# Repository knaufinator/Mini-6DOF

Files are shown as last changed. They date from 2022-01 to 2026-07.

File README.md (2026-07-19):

# Mini-6DOF Stewart Platform

> ## ⚠️ ARCHIVED — this firmware has moved
> The Mini-6DOF firmware now lives in the **unified 6DOF repo** as the **`mini/` variant**, sharing the
> `stewart-core` submodule with the full-system `Controller/` firmware:
> **→ [6DOF-Rotary-Stewart-Motion-Simulator › `mini/`](https://github.com/knaufinator/6DOF-Rotary-Stewart-Motion-Simulator/tree/phoenix/mini)**
> (see [`FIRMWARE.md`](https://github.com/knaufinator/6DOF-Rotary-Stewart-Motion-Simulator/blob/phoenix/FIRMWARE.md) for the variant map).
> This repository is **read-only / no longer active** — all new work (incl. the Phase-3 on-ESP cue engine,
> SOURCE modes, M6P2, and `SERVO:RATE`) happens in the unified repo. Kept for history.





> Desktop-scale 6-DOF Stewart platform powered by hobby servos and an ESP32, running production firmware derived from the [full-scale 6DOF Rotary Stewart Motion Simulator](https://github.com/knaufinator/6DOF-Rotary-Stewart-Motion-Simulator).

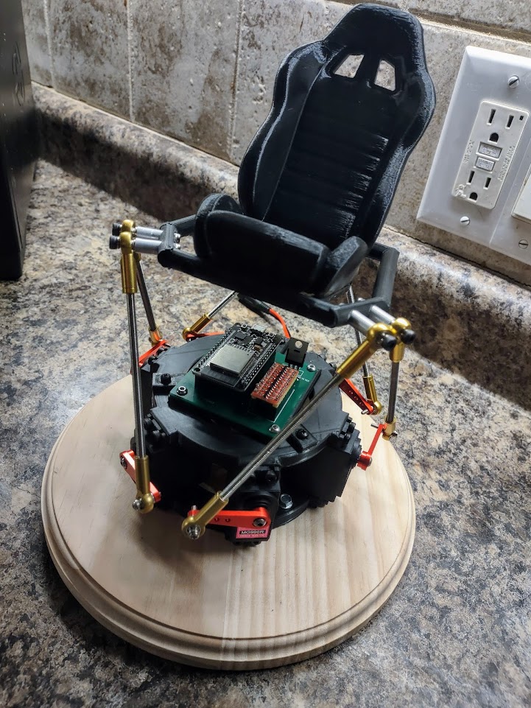
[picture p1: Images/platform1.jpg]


## Overview

The Mini-6DOF is a compact Stewart platform designed for development, testing, and education. It shares the same inverse kinematics engine, serial command API, and binary communication protocol as the full-scale platform — making it a drop-in test bed for firmware and desktop app development.

The `Controller/` firmware is a native ESP-IDF v5.2 project (phoenix branch rewrite) that replaces the original Arduino sketch with a production-grade implementation featuring proper IK workspace probing, binary protocol support, and full compatibility with the [desktop HIL control app](https://github.com/knaufinator/6DOF-Rotary-Stewart-Motion-Simulator/tree/main/app).

### What's New (Phoenix Branch)

- **ESP-IDF native firmware** — replaced Arduino `.ino` with proper ESP-IDF v5.2 project
- **Shared IK engine** — same `InverseKinematics.cpp` and `AxisScaling.cpp` as the full-scale controller
- **Automatic workspace probing** — axis scales computed from geometry, no manual tuning
- **Binary protocol** — 15-byte framed packets (0xAA/0x55 + 6×uint16 LE + XOR checksum) at up to 1000 Hz
- **Unified command API** — `VERSION?`, `FINGERPRINT?`, `CONFIG?`, `SCALE?`, `BITS?`, `ZERO`, `ESTOP:SOFT`
- **Desktop app compatible** — works as an HIL entity in the native C++/ImGui control app
- **Runtime configurable** — geometry, servo calibration, bit depth, axis scales — all adjustable over serial

## Repository Layout

| Directory | Contents |
|---|---|
| `Controller/` | **ESP-IDF v5.2 firmware** (production) — see [Controller/README.md](Controller/README.md) |
| `MiniServoController/` | Original Arduino sketch (legacy reference, not maintained) |
| `Android/` | **Android BLE controller app** (Jetpack Compose, phone-as-controller) |
| `3D Parts/` | STL files for 3D-printed servo mounts and seat rails |
| `PCB/` | Custom PCB gerbers and BOM |
| `Images/` | Project photos |

## Quick Start

```bash
# 1. Clone
git clone https://github.com/knaufinator/Mini-6DOF.git
cd Mini-6DOF/Controller

# 2. Build & flash (requires ESP-IDF v5.2)
idf.py set-target esp32
idf.py build
idf.py -p COM6 flash monitor
```

See [Controller/README.md](Controller/README.md) for full build instructions, pinout, and serial commands.

## Hardware

- **MCU**: ESP32 DevKitC (original ESP32, not S3)
- **Servos**: 6 × hobby servos (50 Hz PWM, 800–2200 µs pulse range)
- **Power**: 5V 8A supply for servo rail
- **Servo Enable**: GPIO 27 controls power relay/MOSFET for servo rail
- **Frame**: 3D-printed mounts + Panhard-style linkage rods

### Servo Pinout

| Servo | GPIO | Inverted |
|---|---|---|
| 0 | 15 | Yes |
| 1 | 14 | No |
| 2 | 4 | Yes |
| 3 | 32 | No |
| 4 | 33 | Yes |
| 5 | 5 | No |

### Platform Geometry (mm)

| Parameter | Value | Description |
|---|---|---|
| RD | 15.75 | Base radius |
| PD | 16.00 | Platform radius |
| L1 | 7.25 | Servo horn length |
| L2 | 28.50 | Connecting rod length |
| H | 25.517 | Neutral platform height |
| θ_r | 10° | Base rotation angle |
| θ_p | 30° | Platform rotation angle |

## Android App (Phone-as-Controller)

The `Android/` directory contains a Jetpack Compose BLE controller app that turns your phone into a 6-DOF motion controller. The phone's orientation sensors and accelerometer drive the platform in real time over BLE.

### Features

- **6-axis control** — roll, pitch, yaw from phone orientation; surge, sway, heave from accelerometer
- **Per-axis tuning** — individual enable, scale (0.01–2.0×), and invert toggles for all 6 axes
- **Max angle clamp** — adjustable 1–6° limit on rotation axes
- **Live data display** — real-time sent values shown per axis
- **Send rate** — configurable 1–200 Hz BLE packet rate
- **Persistent settings** — all axis config saved to SharedPreferences, restored on launch
- **Zero/reset** — one-tap reference reset and home button
- **Manual sliders** — 6-axis manual control when not streaming orientation

### BLE Protocol

The app communicates via two BLE characteristics:

| Characteristic | UUID | Payload | Purpose |
|---|---|---|---|
| Motion | `0xFF01` | 12 bytes: 6 × uint16 LE (0–4095) | Manual slider / IMU percent mode |
| Accel | `0xFF03` | 24 bytes: 6 × float32 LE | Orientation + accel (phone-as-controller) |

**Accel characteristic format** (preferred):

| Float | Field | Unit | Source |
|---|---|---|---|
| 0 | Roll | degrees | Phone orientation (game rotation vector) |
| 1 | Pitch | degrees | Phone orientation |
| 2 | Yaw | degrees | Phone orientation |
| 3 | Surge | m/s² | Accelerometer X |
| 4 | Sway | m/s² | Accelerometer Y |
| 5 | Heave | m/s² | Accelerometer Z (gravity subtracted) |

### Building the APK

Open `Android/` in Android Studio, sync Gradle, and build. Requires Android SDK 34+ and a phone with BLE + accelerometer + gyroscope.

### Default Axis Config

| Axis | Enabled | Scale | Notes |
|---|---|---|---|
| Roll | ✓ | 0.50 | Phone tilt left/right |
| Pitch | ✓ | 0.50 | Phone tilt forward/back |
| Yaw | ✗ | 0.50 | Disabled by default (gyro drift) |
| Surge | ✗ | 0.30 | Phone accel X → platform forward/back |
| Sway | ✗ | 0.30 | Phone accel Y → platform left/right |
| Heave | ✗ | 0.30 | Phone accel Z → platform up/down |

## Communication

### Serial (USB CDC) — 115200 baud, 8N1

**Binary (preferred — 15 bytes, up to 1000 Hz):**

| Offset | Size | Field |
|---|---|---|
| 0 | 1 | `0xAA` sync |
| 1 | 1 | `0x55` sync |
| 2 | 12 | 6 × `uint16_t` LE — surge, sway, heave, pitch, roll, yaw (0–4095 default) |
| 14 | 1 | XOR checksum of bytes 2–13 |

**Legacy CSV:** `<v0>,<v1>,<v2>,<v3>,<v4>,<v5>X`

Both protocols are handled simultaneously. The binary packet state machine takes priority; ASCII bytes fall through to the CSV/command parser.

### SimTools Setup

| Setting | Value |
|---|---|
| Interface Type | Serial |
| COM Port | (your ESP32 port, e.g. COM6) |
| Baud Rate | 115200 |
| Output - Bit Range | 12 |
| Output - Type | Decimal |
| Axis Mapping | `x, y, z, Ry, Rx, Rz` |
| Output Format | `<Axis1a>,<Axis2a>,<Axis3a>,<Axis4a>,<Axis5a>,<Axis6a>X` |

### Desktop App (HIL Mode)

The Mini-6DOF works as an HIL entity in the [native desktop app](https://github.com/knaufinator/6DOF-Rotary-Stewart-Motion-Simulator/tree/main/app). The app auto-detects the platform via `FINGERPRINT?` (reports `platform=mini-6dof`) and loads appropriate geometry defaults.

## Serial Commands

All commands use `X` or newline as terminator.

| Command | Response | Description |
|---|---|---|
| `VERSION?` | `VERSION:1.0.0,proto=1,platform=mini-6dof,...` | Firmware version |
| `FINGERPRINT?` | `FINGERPRINT:<MAC>,fw=1.0.0,proto=1,platform=mini-6dof` | Device identity |
| `CONFIG?` | Geometry + servo calibration | Full platform config dump |
| `CONFIG:key=value` | `CONFIG:OK key=value` | Set geometry param (RD, PD, L1, L2, height, theta_r, theta_p) |
| `SCALE?` | `SCALE:s0,s1,s2,s3,s4,s5` | Current axis scales |
| `BITS?` | `BITS:12,max_raw=4095` | Current input bit depth |
| `BITS:N` | `BITS:N,max_raw=...` | Set bit depth (8–16) |
| `SERVO:CENTER=c0,...,c5` | Echo new centers | Calibrate servo center positions (µs) |
| `SERVO:PULSE=value` | Echo new value | Set pulse-per-radian multiplier |
| `ZERO` | `ZERO:OK` | Home all servos to center |
| `ESTOP:SOFT` | Confirmation | Emergency return to center |
| `DBG:1` / `DBG:0` | Confirmation | Enable/disable debug output |

## Relationship to Full-Scale Platform

This project is the desktop-scale companion to the [6DOF Rotary Stewart Motion Simulator](https://github.com/knaufinator/6DOF-Rotary-Stewart-Motion-Simulator). The firmware shares:

- **Inverse kinematics** — same `InverseKinematics.cpp/.h` (Eisele closed-form solution)
- **Axis scaling** — same `AxisScaling.cpp/.h` (geometry-based workspace probing)
- **Serial protocol** — same binary packet format and command API
- **Platform identification** — `FINGERPRINT?` returns `platform=mini-6dof` so the desktop app can distinguish it from the full-scale `platform=stewart-6dof`

The key differences are output stage (LEDC PWM for hobby servos vs. MCPWM step/dir for AC servos) and scale (millimeters vs. hundreds of millimeters).

## License

MIT — see [LICENSE](LICENSE).

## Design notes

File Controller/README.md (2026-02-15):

# Mini-6DOF Controller Firmware

ESP-IDF v5.2 firmware for the ESP32 driving 6 hobby servos via LEDC PWM in a Stewart platform configuration.

## Project Structure

```
Controller/
├── main/
│   ├── main.cpp              # app_main entry point, FreeRTOS tasks, command API
│   ├── InverseKinematics.cpp # Stewart platform IK solver (shared with full-scale)
│   ├── AxisScaling.cpp       # Per-axis scaling + mapRawToPosition() (shared)
│   ├── BleTransport.cpp      # BLE GATT server (motion + accel characteristics)
│   ├── helpers.cpp           # mapfloat utility
│   └── CMakeLists.txt        # Component build config
├── include/
│   ├── InverseKinematics.h   # StewartConfig + PlatformDef structs, IK API
│   ├── AxisScaling.h         # AxisScaleConfig struct, workspace probing API
│   ├── helpers.h             # Pin definitions, servo parameters, timing constants
│   ├── version.h             # Firmware version + platform ID ("mini-6dof")
│   └── debug_uart.h          # Compile-time debug gating (DBG:1 / DBG:0)
├── CMakeLists.txt            # Top-level ESP-IDF project
└── sdkconfig.defaults        # ESP32 config (UART console, FreeRTOS 1kHz)
```

## Hardware

- **MCU**: ESP32 DevKitC (original ESP32 — not ESP32-S3)
- **Servos**: 6 × hobby servos (SG90/MG996R class)
- **PWM**: LEDC peripheral at 50 Hz, 16-bit resolution (~0.3 µs per tick)
- **Pulse range**: 800–2200 µs (center: 1500 µs)
- **Servo enable**: GPIO 27 — controls power relay/MOSFET for servo rail

### Pinout

| Servo | GPIO | LEDC Channel | Inverted |
|---|---|---|---|
| 0 | 15 | 0 | Yes |
| 1 | 14 | 1 | No |
| 2 | 4 | 2 | Yes |
| 3 | 32 | 3 | No |
| 4 | 33 | 4 | Yes |
| 5 | 5 | 5 | No |

| Function | GPIO |
|---|---|
| Servo Enable | 27 |
| E-Stop | 22 |

Inverted servos are mounted mirrored — the firmware applies the sign flip automatically.

## Building

Requires [ESP-IDF v5.2](https://docs.espressif.com/projects/esp-idf/en/v5.2/esp32/get-started/index.html).

```bash
cd Controller
idf.py set-target esp32    # first time only
idf.py build
idf.py -p COM6 flash monitor
```

Replace `COM6` with your ESP32's COM port.

### Build Options

- **Debug output** (enabled by default in `main/CMakeLists.txt`):
  ```cmake
  target_compile_definitions(${COMPONENT_LIB} PRIVATE ENABLE_DEBUG_UART=1)
  ```
  Toggle at runtime with `DBG:1` / `DBG:0` serial commands.

- **Optimization**: `-O2 -ffast-math -fno-exceptions -fno-rtti` set in `main/CMakeLists.txt`.

## Boot Sequence

1. NVS flash init
2. Load Mini-6DOF geometry defaults (RD=15.75, PD=16, L1=7.25, L2=28.5, H=25.517 mm)
3. Probe IK workspace → compute axis scales with 90% safety margin
4. Configure LEDC PWM (50 Hz, 16-bit) on all 6 servo pins
5. Home all servos to center position (1500 µs)
6. 500 ms settle delay → enable servo power (GPIO 27 HIGH)
7. Start serial monitor task on Core 0
8. Print banner with firmware version, geometry, scales, fingerprint
9. Main loop idles — all motion is interrupt-driven from serial input

## Communication Protocol

### Binary Packet (preferred — 15 bytes)

| Offset | Size | Field |
|---|---|---|
| 0 | 1 | `0xAA` sync |
| 1 | 1 | `0x55` sync |
| 2 | 12 | 6 × `uint16_t` LE (surge, sway, heave, pitch, roll, yaw) |
| 14 | 1 | XOR checksum of bytes 2–13 |

Default input range: 0–4095 (12-bit). Adjustable via `BITS:N` command.

### Legacy CSV

`<v0>,<v1>,<v2>,<v3>,<v4>,<v5>X`

Comma-separated raw values terminated by `X`. Also used for command queries (e.g. `VERSION?X`).

### BLE (Android App)

The firmware includes a BLE GATT server for wireless control from the Android app. Device name: `Mini6DOF`.

| Characteristic | UUID | Size | Purpose |
|---|---|---|---|
| Motion | `0xFF01` | 12 bytes | 6 × uint16 LE (same as serial binary) |
| Accel | `0xFF03` | 24 bytes | 6 × float32 LE (orientation + accel) |

**Accel characteristic pipeline** (phone-as-controller mode):

```
BLE [roll°, pitch°, yaw°, surge_ms2, sway_ms2, heave_ms2]
  → rotation: degrees × DEG_TO_RAD × gain → radians
  → translation: m/s² × gain → mm
  → IK → servo angles → pulse width → LEDC
```

Per-axis gains default to 1.0 for all 6 axes. Connection parameters request 7.5 ms interval for low latency.

### Processing Pipeline

```
Raw input (0–4095) → mapRawToPosition() → physical mm/rad → IK → servo angles → pulse width → LEDC
```

`mapRawToPosition()` maps the unsigned integer range to ± physical displacement using per-axis scales derived from geometry. Rotation axes are automatically converted to radians.

## Serial Commands

| Command | Description |
|---|---|
| `VERSION?` | Firmware version, protocol version, platform ID, build date |
| `FINGERPRINT?` | MAC-based device ID + version + platform for handshake |
| `CONFIG?` | Dump geometry (RD, PD, L1, L2, H, θ_r, θ_p) + servo calibration |
| `CONFIG:key=value` | Set geometry param — auto-recomputes axis scales |
| `SCALE?` | Query current per-axis scales |
| `BITS?` | Query current input bit depth |
| `BITS:N` | Set input bit depth (8–16), updates max raw value |
| `SERVO:CENTER=c0,c1,c2,c3,c4,c5` | Set per-servo center calibration (µs) |
| `SERVO:PULSE=value` | Set pulse-per-radian multiplier |
| `ZERO` | Home all servos to center |
| `ESTOP:SOFT` | Emergency return to center |
| `DBG:1` / `DBG:0` | Enable/disable debug output |

## FreeRTOS Tasks

| Task | Core | Priority | Purpose |
|---|---|---|---|
| `SerialMonitor` | 0 | 5 | UART RX → binary/CSV parser → motion update |
| `app_main` | 0 | 1 | Init + idle watchdog loop |

Motion updates happen synchronously inside the serial monitor task — when a complete packet is received, it immediately runs the IK pipeline and updates all 6 servo PWM outputs.

## Shared Code

The IK and axis scaling modules are identical to the [full-scale controller](https://github.com/knaufinator/6DOF-Rotary-Stewart-Motion-Simulator/tree/main/Controller):

| File | Purpose |
|---|---|
| `InverseKinematics.cpp/.h` | Closed-form Eisele IK solver, `StewartConfig`, `PlatformDef` |
| `AxisScaling.cpp/.h` | Geometry-based workspace probing, `mapRawToPosition()` |

These can be kept in sync by copying from the main project. The only platform-specific code is in `main.cpp` (LEDC servo output vs. MCPWM step/dir) and `helpers.h` (pin definitions).

## Differences from Full-Scale Controller

| Feature | Mini-6DOF | Full-Scale |
|---|---|---|
| **Output** | LEDC PWM (50 Hz hobby servo) | MCPWM step/dir (AC servo + gearbox) |
| **MCU** | ESP32 | ESP32-S3 |
| **Scale** | ~30 mm workspace | ~350 mm workspace |
| **Actuators** | Direct-drive hobby servos | 750W AC servos + 50:1 planetary |
| **BLE** | Yes — Android app control (phone-as-controller) | No |
| **Ethernet** | No | W5500 SPI (opt-in) |
| **WiFi** | No (can be enabled) | ESP-IDF WiFi STA |
| **Motion cueing** | Not included | Biquad washout filters |
| **E-stop** | Software only | Hardware GPIO + software |

## Troubleshooting

```bash
idf.py --version                    # verify ESP-IDF v5.2
idf.py fullclean && idf.py build    # clean rebuild after config changes
idf.py -p COM6 flash                # explicit port
idf.py monitor                      # serial monitor (Ctrl+] to exit)
```

**Servo jitter**: Check power supply — hobby servos under load can brown out if the supply is undersized. Use a dedicated 5V 8A supply, not USB power.

**No serial output**: Verify `CONFIG_ESP_CONSOLE_UART_DEFAULT=y` in `sdkconfig.defaults`. The original ESP32 uses UART0, not USB Serial JTAG.

## License

MIT — see [LICENSE](../LICENSE).

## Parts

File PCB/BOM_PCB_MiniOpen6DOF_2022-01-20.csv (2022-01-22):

ID | Name | Designator | Footprint | Quantity | Manufacturer | Supplier Part | Price
1 | ESP32 | ESP32 | ESP32_DEVKIT | 1
2 | HEADER_3x6 | J1 | 3X6_PIN_HEADER_2.54MM | 1
3 | 8_Logic_Level_Bidirectional s | P4 | 8_CH_BID_LOGIC_LEVEL_SHIFTER | 1
4 | IRLZ44N | Q1 | TO-220AB | 1
5 | 0.68k ohm | R1 | RESISTOR 1/4WATT 1K | 1
6 | 10k ohm | R2 | RESISTOR 1/4WATT 1K | 1
7 | PINHEADER1X2 | U1 | PINHEADER1X2 | 1

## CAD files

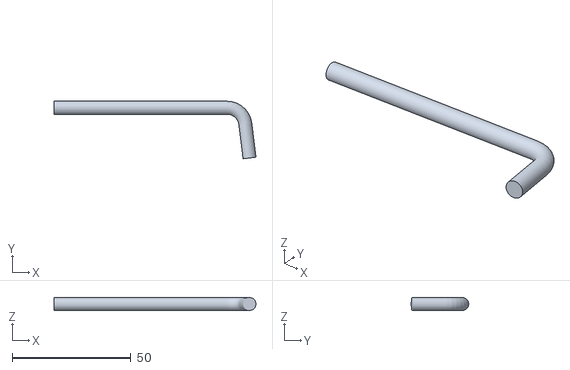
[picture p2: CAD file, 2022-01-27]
3D Parts/Lower Seat Rail.stl
85.2 x 24.3 x 5.47

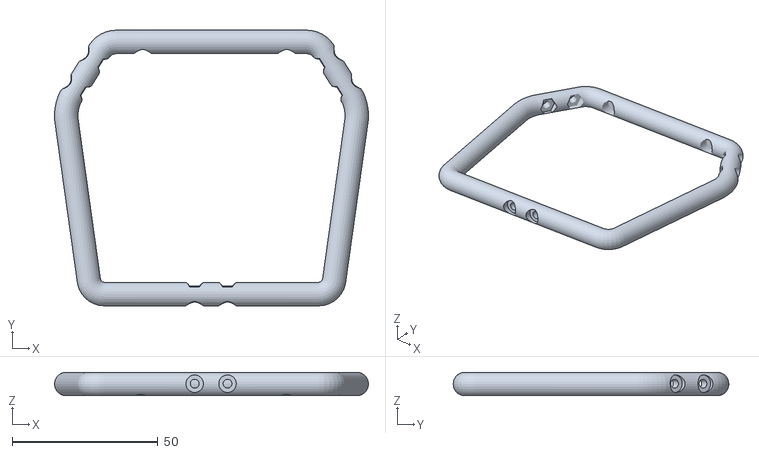
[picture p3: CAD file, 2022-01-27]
3D Parts/Seat Rail.stl
107.6 x 94.4 x 8.04

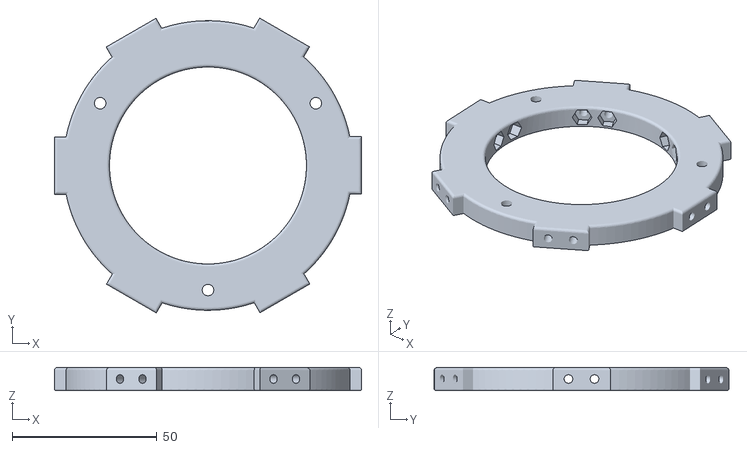
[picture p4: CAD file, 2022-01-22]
3D Parts/Servo Motor Mount.stl
106.0 x 101.8 x 8.00

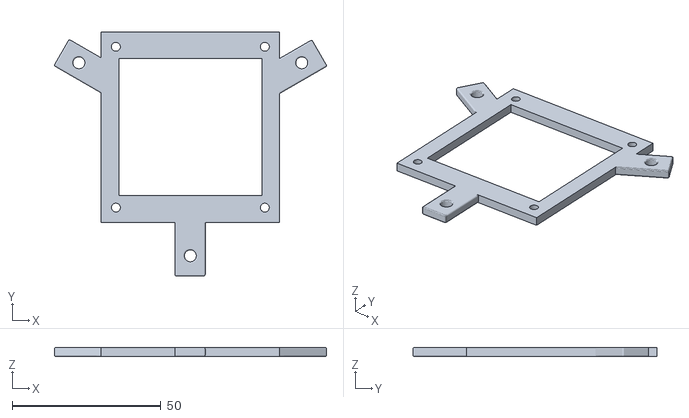
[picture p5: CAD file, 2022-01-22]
3D Parts/pcb mount v1.stl
91.3 x 82.0 x 3.00

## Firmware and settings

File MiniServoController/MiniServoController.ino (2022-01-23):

#include <sstream>
#include <Preferences.h>
#include <Bounce2.h>
#include <BLEDevice.h>
#include <BLEUtils.h>
#include <BLEServer.h>  
#include <ESP32Servo.h>
#include "soc/timer_group_struct.h"
#include "soc/timer_group_reg.h"

#include <BLE2902.h>
#include <cstring>
#include "freertos/FreeRTOS.h"
#include "freertos/timers.h"
#include "helpers.h"

using namespace std;

 
BLEServer* pServer = NULL;
BLECharacteristic* pPostionCharacteristic = NULL;
BLECharacteristic* pPauseCharacteristic = NULL;
  
//CPU tasks, all GPIO for motors is on 2nd CPU, this frees main CPU to process position data and talk to PC and BLE client
TaskHandle_t InterfaceMonitorTask;
TaskHandle_t GPIOLoopTask;
TimerHandle_t wtmr;

int servoEnablePin = 27;

Servo servo[6];
const int pwmMotorPins[] = {15,14,4,32,33,5};   
const  float servoPulseMult=400/(pi/4);
static int zero[6]={1500,1500,1500,1500,1500,1500};
#define MAX 2200
#define MIN 800


//max angle to allow the platform arms travel in degrees ie +-60 degrees. 
const float servo_min=radians(-60),servo_max=radians(60);
static long servo_pos[6];

//current target from pc, modified from 2 seperate tasks/cores
static volatile float arr[6]={0,0,0, 0,0,0};


//parses the data packet from the pc => x,y,z,Ry,Rx,RZ
void process_data ( char * data)
{ 
    int i = 0; 
    char *tok = strtok(data, ",");
    
    while (tok != NULL) {
      double value = (float)atof(tok);
      float temp = 0.0;
          
      if(i == 2)
        temp =mapfloat(value, 0, 4094, -4, 4);//hieve 
      else if(i > 2)//rotations, pitch,roll,yaw
        temp = mapfloat(value, 0, 4094, -10, 10) *(pi/180.0);
      else//sway,surge
        temp = mapfloat(value, 0, 4094, -7, 7); 

        arr[i++] = temp;
      
        tok = strtok(NULL, ",");
    }   

    setPos();
} 
class MyServerCallbacks: public BLEServerCallbacks {
    void onConnect(BLEServer* pServer) {
    
     
    };

    void onDisconnect(BLEServer* pServer) {
        BLEDevice::startAdvertising();
    }
};

class MyCallbacks: public BLECharacteristicCallbacks {
    void onWrite(BLECharacteristic *pCharacteristic) {
      std::string value = pCharacteristic->getValue();

       Serial.print(value.c_str());

      if (value.length() > 0) {
        char* c = strcpy(new char[value.length() + 1], value.c_str());
        process_data (c);          
      }
    }
};

void setPos(){  

 Serial.println("SetPos");
  
    //Platform and Base Coords
    for(int i = 0; i < 6; i++)
    {    
        long x = 0;
        float alpha = getAlpha(i,arr);

      
         if(i==INV1||i==INV2||i==INV3){
           // x = constrain(zero[i] + (alpha)*servoPulseMult, MIN,MAX);

             x = strictMap(zero[i] + (alpha)*servoPulseMult, MIN, MAX ,MIN, MAX);
          }
          else{
            //x = constrain(zero[i] - (alpha)*servoPulseMult, MIN,MAX);
          
          
              x = strictMap(zero[i] - (alpha)*servoPulseMult, MIN, MAX ,MIN, MAX);
          }
          
          servo_pos[i] = x;               
    }

    for(int i = 0; i < 6; i++)
    {
      servo[i].writeMicroseconds(servo_pos[i]);

      Serial.print(servo_pos[i]);
      Serial.print(",");
    }

    Serial.println("");
}

long strictMap(long val, long inmin, long inmax, long outmin, long outmax)
{
  if (val <= inmin) return outmin;
  if (val >= inmax) return outmax;
  return (val - inmin)*(outmax - outmin)/(inmax - inmin) + outmin;
}

//reset timer
void ping( TimerHandle_t xTimer )
{ 
    //Resets the watchdog timer in the ESP32/rtos
    //this is needed in order not have the thing reset every few seconds.
    TIMERG0.wdt_wprotect=TIMG_WDT_WKEY_VALUE;
    TIMERG0.wdt_feed=1;
    TIMERG0.wdt_wprotect=0;

    //Restart timer for this method
    xTimerStart(wtmr, 0);
}

//setup BLE access notify service and configuration characteristics 
void setupBle(){
  
  Serial.println("Starting BLE init!");

  BLEDevice::init("Mini Open 6DOF");
  BLEServer *pServer = BLEDevice::createServer();
  pServer->setCallbacks(new MyServerCallbacks());

  BLEService *pService = pServer->createService(SERVICE_UUID);
  pPostionCharacteristic  = pService->createCharacteristic(
                      POSITIONCHARACTERISTIC_UUID,                 
                      BLECharacteristic::PROPERTY_WRITE 
                    );
                                       
  pPostionCharacteristic->addDescriptor(new BLE2902());
  pPostionCharacteristic->setCallbacks(new MyCallbacks());
  pService->start();


  BLEAdvertising *pAdvertising = BLEDevice::getAdvertising();
  pAdvertising->addServiceUUID(SERVICE_UUID);
  pAdvertising->setScanResponse(true);
  pAdvertising->setMinPreferred(0x12);
  BLEDevice::startAdvertising(); 
}

//start here
void setup(){
 
 Serial.begin(115200); 

//setup turn off pin
pinMode(servoEnablePin, OUTPUT);
digitalWrite(servoEnablePin, false);

  setupBle();

  xTaskCreatePinnedToCore(
                    InterfaceMonitorCode,   /* Task function. */
                    "InterfaceMonitor",     /* name of task. */
                    10000,       /* Stack size of task */
                    NULL,        /* parameter of the task */
                    1,           /* priority of the task */
                    &InterfaceMonitorTask,      /* Task handle to keep track of created task */
                    0);          /* pin task to core 0 */                  

   //setup the outputs for the AC servo controllers
  setupPWMpins();


  //test
// for(int i=0;i<6;i++)
//    { 
//
//   // pinMode(pwmMotorPins[i], OUTPUT);
//
//      
//    }

setPos();

delay(1000);

digitalWrite(27, true);


  //Timer for watchdog reset
  wtmr = xTimerCreate("wtmr", pdMS_TO_TICKS(1000), pdFALSE, (void*)0, reinterpret_cast<TimerCallbackFunction_t>(ping));
  xTimerStart(wtmr, 0);
}

void setupPWMpins() {
    for(int i=0;i<6;i++)
    { 
      servo[i].setPeriodHertz(50);    // standard 50 hz servo
      servo[i].attach(pwmMotorPins[i], MIN, MAX);
    }
}
  
void loop()
{      

//test
//
// for(int i=0;i<6;i++)
//{
//
//digitalWrite(pwmMotorPins[i], true);
//
//}
//
//
// delay(2000); 
// 
// for(int i=0;i<6;i++)
//{
//
//digitalWrite(pwmMotorPins[i], false);
//
//}
//
// delay(2000);
  
}

//reads the serial line,  x,y,z,RX,RY,RZX, Where X is used to indicate end of line. 
//else data will buffer and parsed once a full line is available.
void processIncomingByte (const byte inByte)
{
    static char input_line [MAX_INPUT];
    static unsigned int input_pos = 0;
  
    switch (inByte)
    {
        case 'X':   // end of text
          input_line [input_pos] = 0;  // terminating null byte
          process_data (input_line);          
          input_pos = 0;  
          break;
        case '\r':   // discard carriage return
          break;
        
        default:
          //buffer data
          if (input_pos < (MAX_INPUT - 1))
            input_line [input_pos++] = inByte;
          break;
    } 

    
} 


//Thread that handles reading from PC uart
void InterfaceMonitorCode( void * pvParameters ){
  for(;;){
    
    while (Serial.available () > 0)
      processIncomingByte (Serial.read ());
  } 
}

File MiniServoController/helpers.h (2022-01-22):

#include <math.h>

//calculation helpers
#define DEG_TO_RAD 0.017453292519943295769236907684886
#define RAD_TO_DEG 57.295779513082320876798154814105
#define pi  3.14159265359
#define radians(deg) ((deg)*DEG_TO_RAD)
#define degrees(rad) ((rad)*RAD_TO_DEG)
#define BIT_SET(a,b) ((a) |= (1ULL<<(b)))
#define BIT_CLEAR(a,b) ((a) &= ~(1ULL<<(b)))

//variables for platform positions
static float theta_r = 10;
static float theta_s[6]={150,-90,30, 150,-90,30};
static float theta_p = 30;
static float RD = 15.75;
static float PD = 16;
static float ServoArmLengthL1 = 7.25;
static float ConnectingArmLengthL2 = 28.5;
static float platformHeight = 25.5170749;

//how many pulses per radian of arm movement this value is calibrated to my setup
static float servoPulseMultiplierPerRadian =  800/(pi/4);


//Ble 
#define SERVICE_UUID        "4fafc201-1fb5-459e-8fcc-c5c9c331914b"
#define PAUSECHARACTERISTIC_UUID "beb5483e-36e1-4688-b7f5-ea07361b26a8"
#define POSITIONCHARACTERISTIC_UUID "aeb5483e-36e1-4688-b7f5-ea07361b26a4"

#define NAMESPACE "6dofPrefv1"
#define AXIS1_KEY "Axis1"
#define AXIS2_KEY "Axis2"
#define AXIS3_KEY "Axis3"
#define AXIS4_KEY "Axis4"
#define AXIS5_KEY "Axis5"
#define AXIS6_KEY "Axis6"

//special pins
#define ESTOPPIN 22
#define ESTOPDEBOUNCETIME 10
//Deine the 3 motors that are running counter clockwise
#define INV1 0
#define INV2 2
#define INV3 4

//pulse width minimum length
#define MICRO_INTERVAL_FAST  10
#define MICRO_INTERVAL_SLOW  20000
#define MICRO_INTERVAL_BLE_SEND  10000000
#define ESTOP_RATE_LIMIT_TIME 3000

// how much serial data we expect before a newline
#define MAX_INPUT 60
   
//used to hold current status of a motor
struct acServo {
  int stepPin;
  int dirPin;
  bool pinState;
  long currentpos;
  long targetpos;  
};

float rateLimit(float currentSample,float lastSample);
float mapfloat(double x, double in_min, double in_max, double out_min, double out_max);
float getAlpha(int i,volatile float arr[]);

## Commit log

2022-01-22 Optimize 3D model
    Adjust the edges and corners and smooth the surface.
    [Seat Rail.stl, Servo Motor Mount.stl, pcb mount v1.stl]
2022-01-22 Update Seat Rail.stl
    was not the seat rail,... but the main chassis
    [Seat Rail.stl]
2022-01-22 clean up, and place lower seat rail
    [Chassis Frame.stl, Lower Seat Rail.stl]
2022-01-23 Android Upload
    [top v58.f3d]
2022-01-23 limit adjust for buffer overflow prevention
    [MiniServoController.ino]
2022-01-24 Update Seat Rail.stl
    [Seat Rail.stl]
2022-01-27 Detail optimization
    [Lower Seat Rail.stl, Seat Rail.stl]
2026-02-14 Phoenix branch: ESP-IDF firmware, production README, .gitignore
    - Rewrote root README as production docs for main branch release
    - Added Controller/README.md with full firmware documentation
    - Added Controller/ ESP-IDF v5.2 native firmware (replaces Arduino sketch)
    Shared IK engine, binary protocol, unified command API, LEDC PWM servo output
    - Added .gitignore (build artifacts, IDE, OS, Android build)
    [helpers.h, main.cpp]
2026-02-14 feat: configurable telemetry rate, handshake silence, serial buffer + slew rate tuning, Android Kotlin rewrite
    Controller firmware:
    - Added TELRATE:N command (1-100 Hz) to dynamically set telemetry rate
    - Added TELRATE? query to read current rate
    - Telemetry silent on boot until app sends TELRATE:N after handshake
    - Increased MAX_SERIAL_INPUT from 60 to 256 bytes
    - Binary header leak fix: return after 0xAA/0x55 detection
    - Increased slew rate limiter from 0.8 to 5.0 mm/cycle (300mm/sec at 60Hz)
    - Added BLE transport layer (BleTransport.h/.cpp)
    Android: Complete rewrite from Java to Kotlin with Jetpack Compose
    - BLE connection, IMU sensor, and platform control screens
    - MVVM archite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
    [ControlScreen.kt]
2026-02-15 feat: 6-axis BLE phone-as-controller with persistent settings
    Android App:
    - 6-axis control: roll/pitch/yaw from orientation, surge/sway/heave from accelerometer
    - Per-axis enable, scale (0.01-2.0x), and invert toggles
    - Max angle clamp adjustable 1-6 degrees
    - Live sent values displayed per axis in Control screen
    - Settings auto-saved to SharedPreferences on every change
    - Send rate configurable 1-200 Hz
    - BLE accel characteristic (0xFF03): 24 bytes, 6x float32 LE
    Firmware:
    - BLE GATT server with motion (0xFF01) and accel (0xFF03) characteristics
    - 6-axis accel pipeline: rotation deg->rad, translation m/s2->mm
    - Per-axis gains default 1.0 for all axes
    - Slew rate limiting and IK workspace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
    [ControlScreen.kt]
2026-02-16 feat: add PCBv1/ folder for original board with optimized firmware
    - Copied Controller/ to PCBv1/ for users with the original v1 PCB
    - Optimized for PCBv1 hardware:
    - 200Hz motion loop decoupled from telemetry (was coupled at 50Hz)
    - 14-bit default input depth (4x finer than 12-bit)
    - Integer math usToDuty() (no float division in hot path)
    - Slew rate tuned for 200Hz: 2mm/cycle = 400mm/s max velocity
    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
2026-02-16 Revert "feat: add PCBv1/ folder for original board with optimized firmware"
    This reverts commit 022629d974c698dceac6d276a1d1283ac4b6c8ab.
    [helpers.h, main.cpp]
2026-07-18 feat(firmware): COBS transport + on-device motion-cue playback + 2MB repartition
    - CobsTransport: COBS-framed CH_DATA/CH_CMD/CH_TEL/CH_LOG/CH_RESP over UART0 @921600
    (cobs.h codec); data/cmd handlers registered in app_main.
    - On-device demo playback: embedded baked sequence (laps123_moderate.m6p, 3 Nurburgring
    laps @50Hz, ~275KB), parseSequence()/PlaybackTask, PLAY:START/STOP/LOOP/STATUS/BOOT,
    and play_on_boot (NVS) auto-start.
    - partitions.csv: custom 2MB table with a larger factory app (0x1E0000) so the embedded
    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
    [partitions.csv]
2026-07-19 feat(fw): Phase 3 — on-ESP high-rate cue engine + SOURCE modes + M6P2 + 4MB (#5)
    * feat(fw): Phase 3 — on-ESP high-rate cue engine, SOURCE modes, M6P2, 4MB
    Decoupled producer/consumer cue engine + runtime servo-rate profile, per
    DECISIONS rounds 3/4 and MCU_HIFI_CUEING.md (hold-only variant).
    Submodule: bump stewart-core to feat/cue-params (output-stage cue params).
    1) 4MB no-OTA repartition (offsets preserved so calibration + mca_cfg survive):
    - sdkconfig.defaults 2MB -> 4MB.
    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
    [partitions.csv]
